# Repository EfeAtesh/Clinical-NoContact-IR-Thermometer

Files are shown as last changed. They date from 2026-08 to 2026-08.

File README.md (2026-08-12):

# Clinical Non-Contact Infrared Thermometer
> **Klinik Temassız Kızılötesi Termometre Projesi** (๑•̀ㅂ•́)و✧  
> *BME425 Biyomedikal Mühendisliği Projesi | Group 1 (01-MIY-2526S)*

---

## ( ° ᴗ ° ) Project Overview

This repository contains the design, hardware specifications, PCB Gerber files, 3D mechanical enclosure models, testing procedures, circuit schematics, physical prototype photos, etched PCB assembly images, and embedded C++ firmware for a **Clinical-Grade Non-Contact Infrared (IR) Thermometer**.

The device is engineered according to international medical device standards, specifically **EN ISO 80601-2-56:2017** (*Particular requirements for basic safety and essential performance of clinical thermometers for body temperature measurement*).

---

## (ノ◕ヮ◕)ノ*::・゜ Prototype & Hardware Gallery

| Handheld Prototype (Side View) | OLED Temperature Display |
| :---: | :---: |
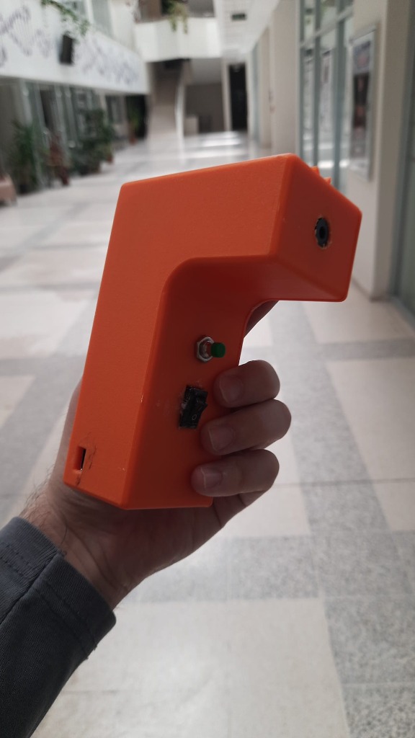
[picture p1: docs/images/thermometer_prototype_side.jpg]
Handheld Prototype
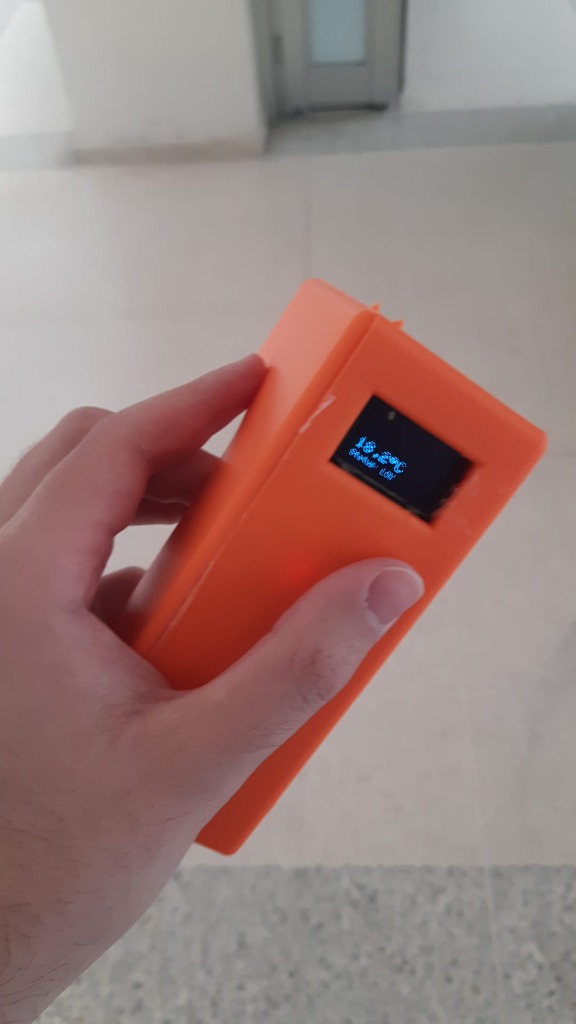
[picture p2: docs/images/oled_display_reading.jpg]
OLED Display
|  |  |
| *Ergonomic 3D enclosure with trigger button, power switch & IR sensor aperture* | *Real-time temperature readout (18.2 °C) & battery status on SSD1306 OLED* |

| Assembled PCB (Top / Component View) | Etched PCB (Bottom / Traces View) |
| :---: | :---: |
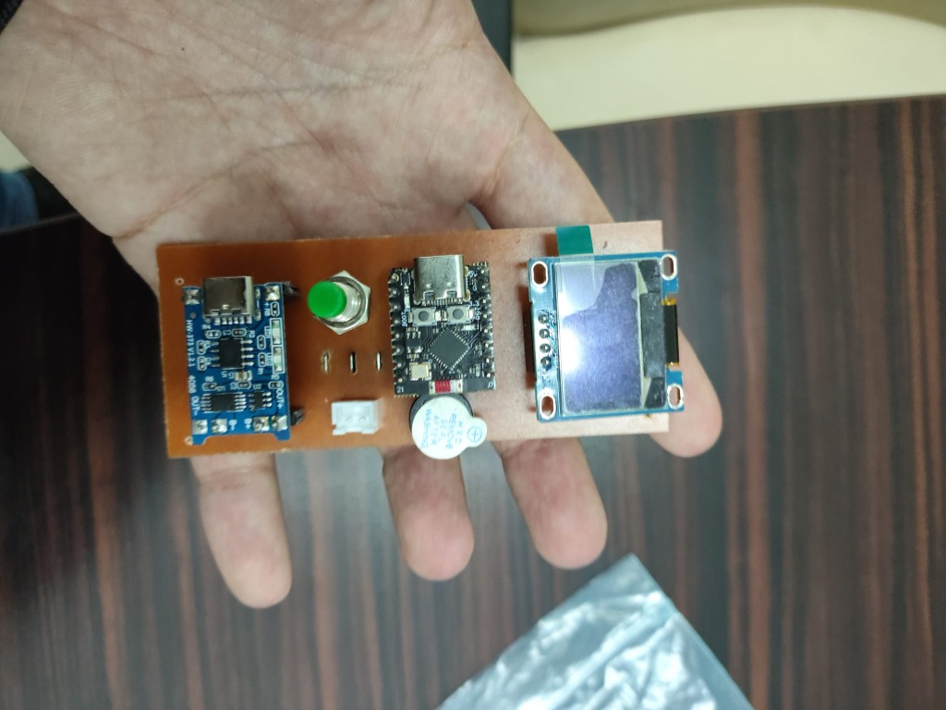
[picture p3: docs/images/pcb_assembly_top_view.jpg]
Assembled PCB
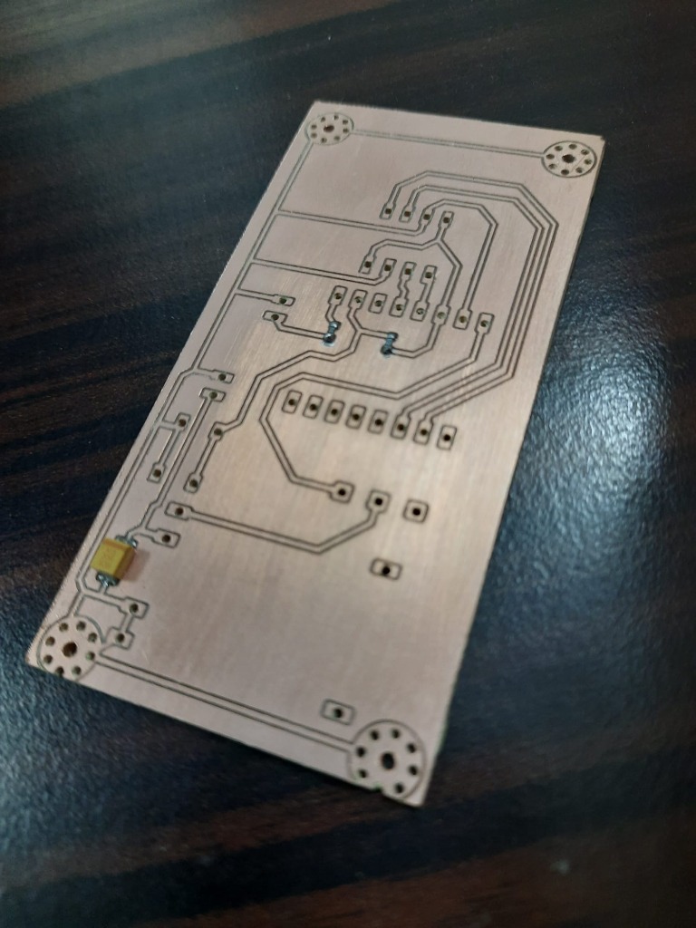
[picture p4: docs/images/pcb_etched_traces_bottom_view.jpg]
Etched PCB Traces
|  |  |
| *Fabricated control board with TP4056, ESP32-C3 Mini, SSD1306 OLED & Buzzer* | *Etched copper PCB traces showing component pads and SMD decoupling capacitors* |

| Circuit Schematic Diagram | Weight Verification (113.17 g) |
| :---: | :---: |
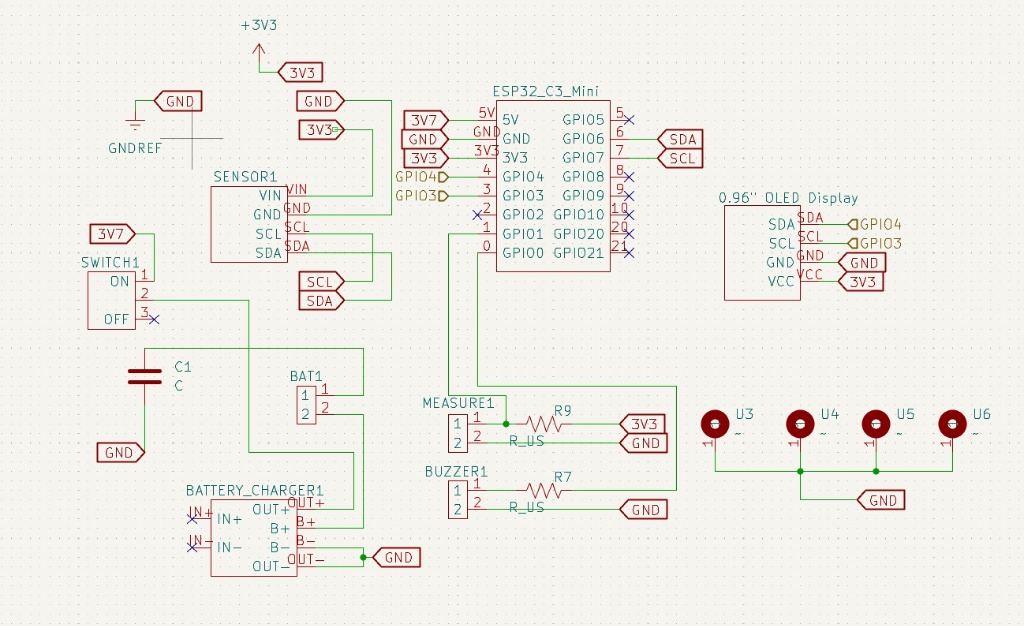
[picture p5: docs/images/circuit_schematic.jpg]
Circuit Schematic
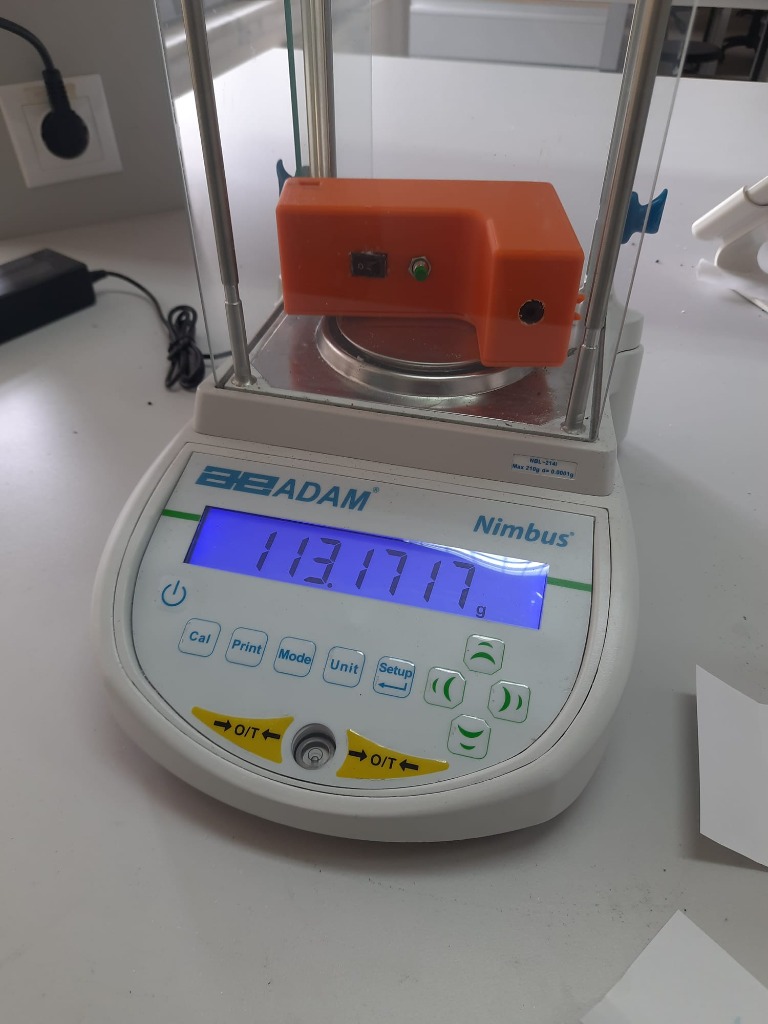
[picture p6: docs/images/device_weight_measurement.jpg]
Weight Measurement
|  |  |
| *KiCad schematic showing ESP32-C3, MLX90614, TP4056, OLED & Buzzer interconnections* | *Precision weight measurement using ADAM Nimbus digital scale (113.1717 g)* |

---

## (っ˘ω˘ς) Firmware & Software Architecture

The embedded system source code is structured under `firmware/` with **Clean Code** architecture principles:
- **Constants & Configuration**: Explicit pin maps (`PIN_I2C_SDA = 8`, `PIN_I2C_SCL = 9`, `PIN_BUTTON = 21`, `PIN_BUZZER = 0`) and fever threshold (`FEVER_THRESHOLD_C = 37.5°C`).
- **UI & Animations**: Boot thermometer filling animation (`playStartupAnimation()`), rotating loading spinner (`showLoadingSpinner()`), slide-in temperature display (`displayResultSlideIn()`), and non-blocking idle heartbeat pulse (`updateIdleHeartbeat()`).
- **Auditory Alerts**: Discrete button beep (`playButtonBeep()`) and 4-beep fever acoustic warning (`triggerFeverAlert()`).

### ( •̀ ω •́ )y Building & Flashing Firmware

#### Option A: PlatformIO (VS Code)
```bash
cd firmware
pio run --target upload
```

#### Option B: Arduino IDE
1. Open [`firmware/thermometer_firmware/thermometer_firmware.ino`](file:///Users/main/Desktop/Microsoft-Staj/Clinical-NoContact-IR-Thermometer/firmware/thermometer_firmware/thermometer_firmware.ino).
2. Install Required Libraries via Library Manager:
   - `Adafruit MLX90614 Library`
   - `Adafruit SSD1306`
   - `Adafruit GFX Library`
3. Select Board: **ESP32C3 Dev Module** (Baud Rate: 115200) and click **Upload**.

---

## ( •̀ ω •́ )✧ Key Specifications & Hardware Architecture

| Component | Description / Part Number | Interface / Specs |
| :--- | :--- | :--- |
| **Microcontroller Unit (MCU)** | ESP32-C3 Mini WiFi & Bluetooth LE Board | I2C / GPIO |
| **Infrared Temperature Sensor** | Melexis GY-906 / MLX90614 Non-Contact IR Sensor | I2C (SDA: GPIO8, SCL: GPIO9) |
| **Display Unit** | 0.96-inch SSD1306 OLED Graphic Display (128x64) | I2C |
| **Power Management** | TP4056 Type-C Lithium Battery Charger Module | Type-C 5V Input |
| **Battery** | Power-Xtra PX302030 3.7V 120mAh 1S Li-Polymer Battery | 3.7V DC |
| **Audio Notification** | 3–24V Active Electronic Buzzer | GPIO Alert Output (GPIO0) |
| **Total Mass** | 113.17 g (verified via laboratory balance) | Ergonomic Handheld |
| **Enclosure** | Custom Ergonomic 3D Printable Housing | Mechanical (`mechanical/`) |

---

## ⚡( ʘ ‿ ʘ )⚡ Circuit Schematic Highlights

The electrical system is designed around the **ESP32-C3 Mini** board:
- **Sensor Connection**: GY-906 (MLX90614) IR sensor communicates via I2C bus (`SDA` -> `GPIO8`, `SCL` -> `GPIO9`).
- **Display Connection**: 0.96" OLED display shares the I2C bus (`GPIO8`/`GPIO9`) powered at 3.3V.
- **Power Path**: 3.7V Li-Po battery connects through an ON/OFF Rocker Switch (`SWITCH1`) to `BATTERY_CHARGER1` (TP4056) and supplies power to the system.
- **Measurement Trigger**: `MEASURE1` tactile push button on `GPIO21` with pull-up resistor setup.
- **Audio Output**: `BUZZER1` active buzzer connected to `GPIO0` via current-limiting resistor `R7`.

---

## (っ•̀ω•́)っ✎⁾⁾ Repository Navigation Structure

```
Clinical-NoContact-IR-Thermometer/
├── README.md                                    # Main project documentation & specification guide
├── LICENSE                                      # CERN Open Hardware Licence v2 (CERN-OHL-P)
├── .gitignore                                   # OS & editor file exclusion rules
│
├── mechanical/                                  # 3D Mechanical Housing & Enclosure Files (.f3d, .stl, docs)
│   ├── Housing_Design_v10.docx                  # Enclosure design document
│   ├── Housing_Design_v10.pdf                   # Housing design specifications PDF
│   ├── Housing_Assembly.pdf                     # Enclosure assembly instructions
│   ├── Cover_Page.docx                          # Housing cover documentation
│   └── Cover_Page.pdf                           # Housing cover documentation PDF
│
├── firmware/                                    # Embedded C++ Firmware (Clean Code Architecture)
│   ├── platformio.ini                           # PlatformIO configuration & dependency file
│   ├── src/
│   │   └── main.cpp                             # C++ Main Firmware Source Code
│   └── thermometer_firmware/
│       └── thermometer_firmware.ino             # Arduino IDE Sketch File
│
├── hardware/                                    # Electrical & Electronic Engineering
│   ├── datasheets/                              # Component Datasheets
│   │   ├── ESP32-C3_Mini_Board.pdf              # ESP32-C3 MCU datasheet
│   │   ├── MLX90614_IR_Sensor.pdf               # MLX90614 IR temperature sensor datasheet
│   │   ├── SSD1306_OLED_Display.pdf             # SSD1306 0.96" OLED display datasheet
│   │   ├── TP4056_Battery_Charger.pdf           # TP4056 Li-Po charger datasheet
│   │   ├── Power-Xtra_PX302030_LiPo_Battery.pdf # 3.7V 120mAh LiPo battery datasheet
│   │   └── Active_Buzzer.pdf                    # Active electronic buzzer datasheet
│   │
│   └── pcb/                                     # Gerber PCB Fabrication Files
│       ├── Design-F_Cu.gbr                      # Top copper layer
│       ├── Design-B_Cu.gbr                      # Bottom copper layer
│       ├── Design-F_Mask.gbr                    # Top solder mask
│       ├── Design-B_Mask.gbr                    # Bottom solder mask
│       ├── Design-F_Silkscreen.gbr              # Top silkscreen
│       ├── Design-B_Silkscreen.gbr              # Bottom silkscreen
│       ├── Design-F_Paste.gbr                   # Top solder paste
│       ├── Design-B_Paste.gbr                   # Bottom solder paste
│       └── Design-Edge_Cuts.gbr                 # Board outline / edge cuts
│
├── docs/                                        # Documentation & Regulatory Files
│   ├── images/                                  # High-resolution prototype photos & schematics
│   │   ├── thermometer_prototype_side.jpg       # Handheld prototype photo
│   │   ├── oled_display_reading.jpg             # OLED temperature readout photo
│   │   ├── pcb_assembly_top_view.jpg            # Assembled PCB top view photo
│   │   ├── pcb_etched_traces_bottom_view.jpg    # Etched copper PCB bottom view photo
│   │   ├── circuit_schematic.jpg                # KiCad schematic diagram image
│   │   └── device_weight_measurement.jpg        # Digital scale weight measurement photo
│   │
│   ├── reports/                                 # Project plans, design descriptions & final reports
│   │   ├── BME425_Thermometer_Document.pdf      # Detailed thermometer design overview
│   │   ├── Final_Report_Group1.pdf              # Final capstone project report
│   │   ├── Project_Management_Plan.docx         # Project Management Plan (PMP)
│   │   ├── Design_Description.docx              # System Design Description
│   │   ├── System_Requirements.docx             # System requirements specification
│   │   ├── Preliminary_Design_Review.docx       # Preliminary Design Review (PDR)
│   │   ├── Configuration_Item_List.docx         # Configuration management item list
│   │   ├── Group1_Gantt_Chart.xlsx              # Project timeline & Gantt chart
│   │   └── Appendix.docx                        # Documentation appendix
│   │
│   ├── test-procedures/                         # Verification, Validation & Acceptance Testing
│   │   ├── Acceptance_Test_Procedure_ATP.pdf    # Acceptance Test Procedure (ATP)
│   │   ├── Verification_Validation_Test_Procedure_V2TP.pdf # V2TP test procedure
│   │   ├── Verification_Validation_Test_Plan.pdf# Verification & validation test plan
│   │   ├── Power_And_Control_Board_Assembly.pdf # Assembly guide for power/control board
│   │   ├── Assembly_Record.pdf                  # Device assembly records
│   │   ├── Verification_Validation_Test_Procedure_Template.docx # V2TP template
│   │   └── V2TP_Test_Datasheet.xlsx             # Test data recording spreadsheet
│   │
│   ├── standards/                               # Regulatory Medical Standards
│   │   ├── EN_ISO_80601-2-56-2017.pdf           # ISO standard for clinical thermometers (PDF)
│   │   └── EN_ISO_80601-2-56-2017.docx          # ISO standard reference document (Word)
│   │
│   └── sustainability/                          # Sustainability & Ethics Declarations
│       ├── UN_Sustainable_Development_Report.pdf# UN SDG alignment report
│       ├── UN_Sustainable_Development_Affirmation.docx # Sustainability affirmation
│       ├── Sustainable.docx                     # Sustainability impact analysis
│       └── Ethics_Declaration.docx              # Engineering ethics declaration
│   
│   
│
└── archive/                                     # Archival Storage
    └── duplicates/                              # Preserved previous draft versions & duplicates
```

---

## 🩺( ° Q ° ) Medical Standards Compliance

This project complies with **EN ISO 80601-2-56:2017**, which governs:
- Clinical accuracy and repeatability in non-contact body temperature measurements.
- Operational safety, thermal limit protections, and power management.
- Verification & Validation test procedure protocols (V2TP / ATP).

---

## ( ⚗_⚗ ) Verification & Acceptance Testing

Testing procedures are structured under `docs/test-procedures/`:
1. **Acceptance Test Procedure (ATP)**: Validates basic physical and electrical assembly requirements.
2. **Verification & Validation Test Procedure (V2TP)**: Verifies sensor calibration accuracy, thermal response time, audio alerts, and display output against reference laboratory thermometers.
3. **Mass Verification**: Total prototype weight verified at **113.17 g** using ADAM Nimbus precision scale.

---

## (📜 ❛ ֊ ❛) License & Attribution

This project is licensed under the **[CERN Open Hardware Licence Version 2 - Permissive (CERN-OHL-P)](LICENSE)**.  
Developed for **BME425 (01-MIY-2526S) Biomedical Engineering Project**. All rights reserved by Group 1 contributors.

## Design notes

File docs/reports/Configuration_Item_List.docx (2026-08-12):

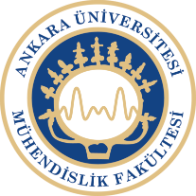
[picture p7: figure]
Inserting image...

Faculty of Engineering

Department of Biomedical Engineering

# Configuration List for The

# Non-Contact Clinical Thermometer

Part Number: 01-MIY-004

Rev-1

Date: 18/12/2025

# CHANGE RECORDS

# FIRST RELEASE

CREATED BY
Name | Title | Date Sign.

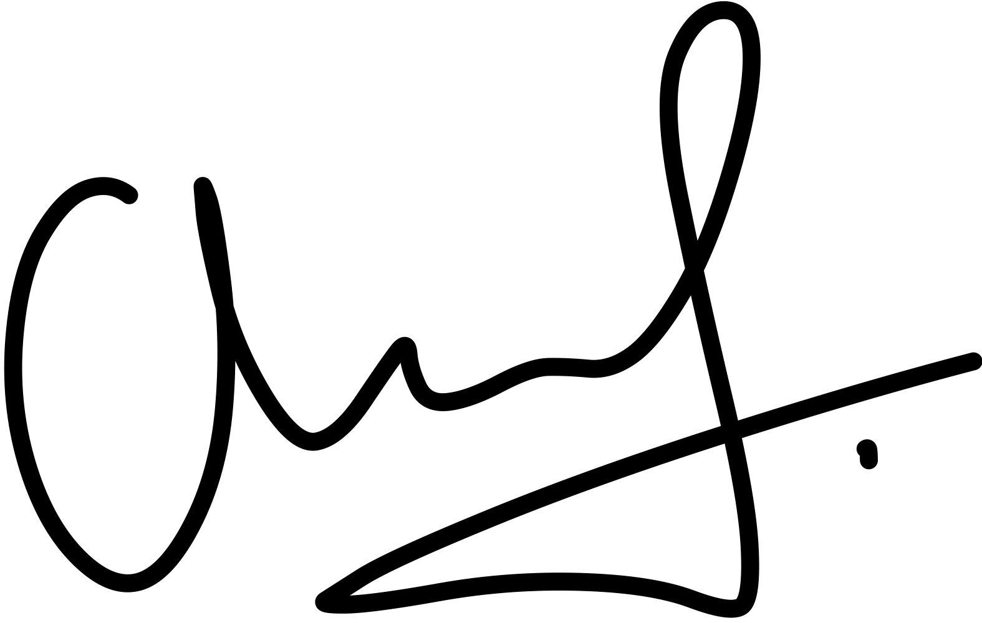
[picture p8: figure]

Augusta Nwosu | Electrical Engineer | 18.12.2025

CHECKED BY
Name | Title | Date Sign.
Fadime Taş | Quality Engineer | 18.12.2025

APPROVED BY
Name | Title | Date Sign.

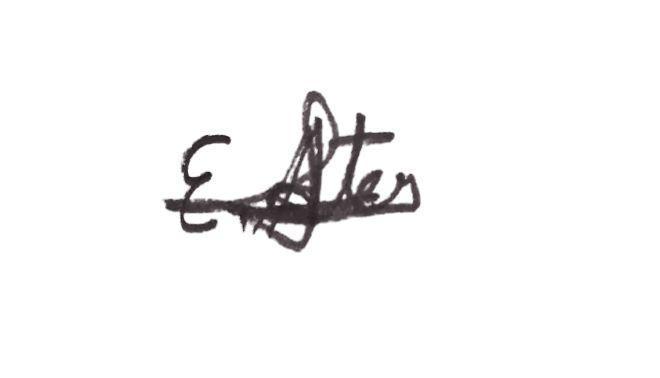
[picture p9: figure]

Efe Ateş | Program Manager | 18.12.2025

# REVISIONS

Rev. No | Change Description | Date | QA Approval

TABLE OF CONTENTS

FIRST RELEASE……………………………………………….………………………………………..2

REVISIONS……………………………………………………………………………………...2

1. PURPOSE…………………………………………………………………………………..4

2. SCOPE……………………………………………………………………………………… 4

3. CONFIGURATION ITEM LIST………………………………………………………….4

4. REFERENCES…………………………………………………………………………….. 5

1. PURPOSE

The purpose of the configuration item list for the non-contact type thermometer is to formally identify, document, and control all hardware and electronic components required for the development, assembly, and maintenance of the device. By listing each component with its corresponding part number and item description, the configuration item list ensures traceability, consistency, and accuracy throughout the product lifecycle. This documentation supports effective procurement, quality assurance, and change management by providing a single, authoritative reference that aligns design specifications with the actual components used in the thermometer.

2. SCOPE

The scope of the configuration item list covers all materials and components necessary for the non-contact thermometer, including sensing elements, electronic modules, mechanical parts, power components, and interconnections. For each item, the list provides the relevant part number, a clear description, and reference links to approved suppliers for purchasing the materials. The scope is limited to components that directly contribute to the functionality, assembly, and verification of the thermometer, and it serves as a reference for all engineers during design and manufacturing activities.

3. CONFIGURATION ITEM LIST

Table 1: Configuration Item List for Non Contact Thermometer

Item No | Part Number | Description
1 | 01-PRT-001 | MCU Kit, ESP32 C3 Mini
2 | 01-PRT-002 | MLX90614, Infrared Camera Sensor
3 | 01-PRT-003 | TP4056, Battery Charger Module
4 | 01-PRT-004 | Display Kit, 0.96” LCD Display
5 | 01-PRT-005 | On/Off Slider Switch
6 | 01-PRT-006 | Measurement Button
7 | 01-PRT-007 | Buzzer
8 | 01-PRT-008 | Resistor
9 | 01-PRT-009 | JST Connector
10 | 01-PRT-010 | Lithium Ion Battery
11 | 01-PRT-011 | Sensor PCB
12 | 01-PRT-012 | Housing Assembly

4. REFERENCES
1. Microcontroller – ESP 32 C3 super mini - https://www.direnc.net/esp32-c3-mini-wifi-bluetooth-modulu
2. Infrared camera sensor - MLX90614 - (https://www.robotistan.com/gy906-mlx90614-kizilotesi-sensoru-modulu?language=tr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)https://www.robotistan.com/gy906-mlx90614-kizilotesi-sensoru-modulu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
3. Battery charger – TP4056 - https://www.robotistan.com/tp4056-type-c-1s-37v-lipo-li-ion-pil-sarj-devresi
4. Battery and buzzer connector – JST connector - https://www.robotistan.com/ds1066-2mrw6xb-2-pin-90-derece-pcb-jst-konnektor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
5. LCD Display - (https://www.direnc.net/128x64-096-4-pin-oled-grafik-lcd-ekran-ssd1306-i2c-beyaz)https://www.direnc.net/128x64-096-4-pin-oled-grafik-lcd-ekran-ssd1306-i2c-beyaz
6. ON/OFF Slider Switch - https://www.direnc.net/surgulu-on-off-switch-180
7. Begin Measurement Button - https://www.direnc.net/6x6-05mm-tach-buton-4-bacak
8. Resistor – 1kohm, 10kohm - Buy 0R 5% 1W 2512 SMD Resistor at a Good Price - Direnc.net® (https://www.direnc.net/0r-5-1w-2512-smd-direnc-4000-adet)
9. Active Buzzer - 3-24V Circuit 22.6mm Ear Buzzer - Buy Black at a Reasonable Price - Direnc.net® (https://www.direnc.net/3-24v-devreli-40mm-kulakli-buzzer-siyah)

Doc. No: Part Number: 11-MIY-004 Configuration Item List for Non Contact Type Clinical Thermometer Rev:01 Page / ALL RIGHTS RESERVED. REPRODUCTION OR ISSUE TO THIRD PARTIES IN ANY FORM WHATEVER IS NOT PERMITTED WITHOUT WRITTEN AUTHORITY FROM THE PROPRIETORS.

ALL RIGHTS RESERVED. REPRODUCTION OR ISSUE TO THIRD PARTIES IN ANY FORM WHATEVER IS NOT PERMITTED WITHOUT WRITTEN AUTHORITY FROM THE PROPRIETORS.

MİKROELEKTRONİK, GÜDÜM VE ELEKTRO-OPTİK GRUBU MICROELECTRONICS, GUIDANCE AND ELECTRO-OPTICS DIVISION

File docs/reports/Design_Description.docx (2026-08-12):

Inserting image...

Faculty of Engineering

Department of Biomedical Engineering

# Non-Contact Type Clinical Thermometer

# Design Description

Part Number: 11-MIY-003

Rev-1

Date: 24/11/2025

# CHANGE RECORDS

## FIRST RELEASE

CREATED BY
Name | Title | Date Sign.
Gülşen Demir | System Engineer | 24.11.2025


Augusta Nwosu | Electrical Engineer | 24.11.2025

CHECKED BY
Name | Title | Date Sign.
Fadime Taş | Quality Engineer | 24.11.2025

APPROVED BY
Name | Title | Date Sign.

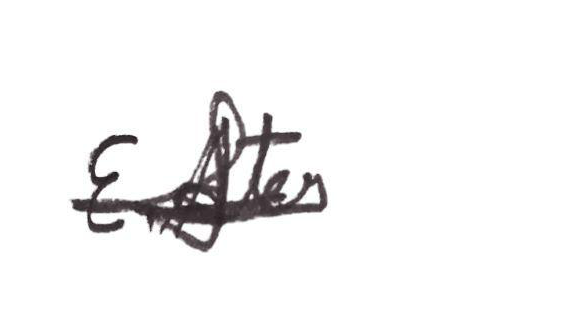
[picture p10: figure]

Efe Ateş | Program Manager | 24.11.2025

## REVISIONS

Rev. No | Change Description | Date | QA Approval

TABLE OF CONTENTS

CHANGE RECORDS 2

FIRST RELEASE 2

REVISIONS 2

1. SCOPE 4

2. DESCRIPTION 4

3.REFERENCES 5

4.SYSTEM ARCHITECTURE 6

4.1. PHYSICAL (BLOCK DIAGRAM) 6

4.2. FUNCTIONAL (OPERATION) 7

4.3. PRINCIPLE OF OPERATION 8

# 1. SCOPE

Body temperature is one of those basic but vital signs that tells us a lot about someone's health, right alongside blood pressure and pulse. These days, with hygiene concerns front and centre and the need for quick assessments, the old-fashioned contact thermometers feel slow and raise worries about spreading germs.

That's where a non-contact infrared thermometer comes in. You simply point it at someone's forehead from a short distance, and the infrared sensors do the rest, giving you an accurate reading instantly without ever touching the skin. It's a significant change for health monitoring.

# 2. DESCRIPTION

The non-contact thermometer measures forehead temperature by detecting infrared radiation emitted from the skin. This radiation is captured by the infrared camera module, where the IR sensors generate an analogue signal. The signal is immediately processed through an internal LNA, ADC, and DSP to produce accurate digital temperature data.

The processed signal is sent to the ESP32-C3 Mini, which performs final calculations and system control through its embedded firmware. After computing the temperature, the microcontroller transmits the result to the OLED display via serial communication, ensuring clear and fast visual output.

The device is powered by a rechargeable Li-ion battery. A dedicated charging circuit receives 5 V from a USB source and manages safe charging of the 3.7 V battery that runs the entire system. This enables fully portable operation.

User-interaction components, including the ON/OFF switch, buzzer, and reset button, are connected directly to the microcontroller for simple and reliable control. A USB programming interface on the ESP32-C3 Mini allows easy firmware updates when required.

This configuration provides a compact, efficient, and touch-free solution for quick and accurate forehead temperature measurement.

# 3.REFERENCES

3.1. 01-TRM-800: System Requirement Specification

3.2. ISO 80601-2-56:2017 : Particular requirements for basic safety and essential performance of clinical thermometers for body temperature measurement

3.3. IEC 60601–1:2005+A1:2012 : Medical electrical equipment - Part 1: General requirements for basic safety and essential performance

3.4. IEC 60601‐1‐2:2014 : Medical electrical equipment — Part 1-2: General requirements for basicsafety and essential performance — Collateral Standard: Electromagnetic disturbances ,Requirements and tests

3.5. ASTM E1965-98(2016) – Standard Specification for Infrared Thermometers for Intermittent Determination of Patient Temperature.

# 4.SYSTEM ARCHITECTURE

## 4.1. PHYSICAL (BLOCK DIAGRAM)

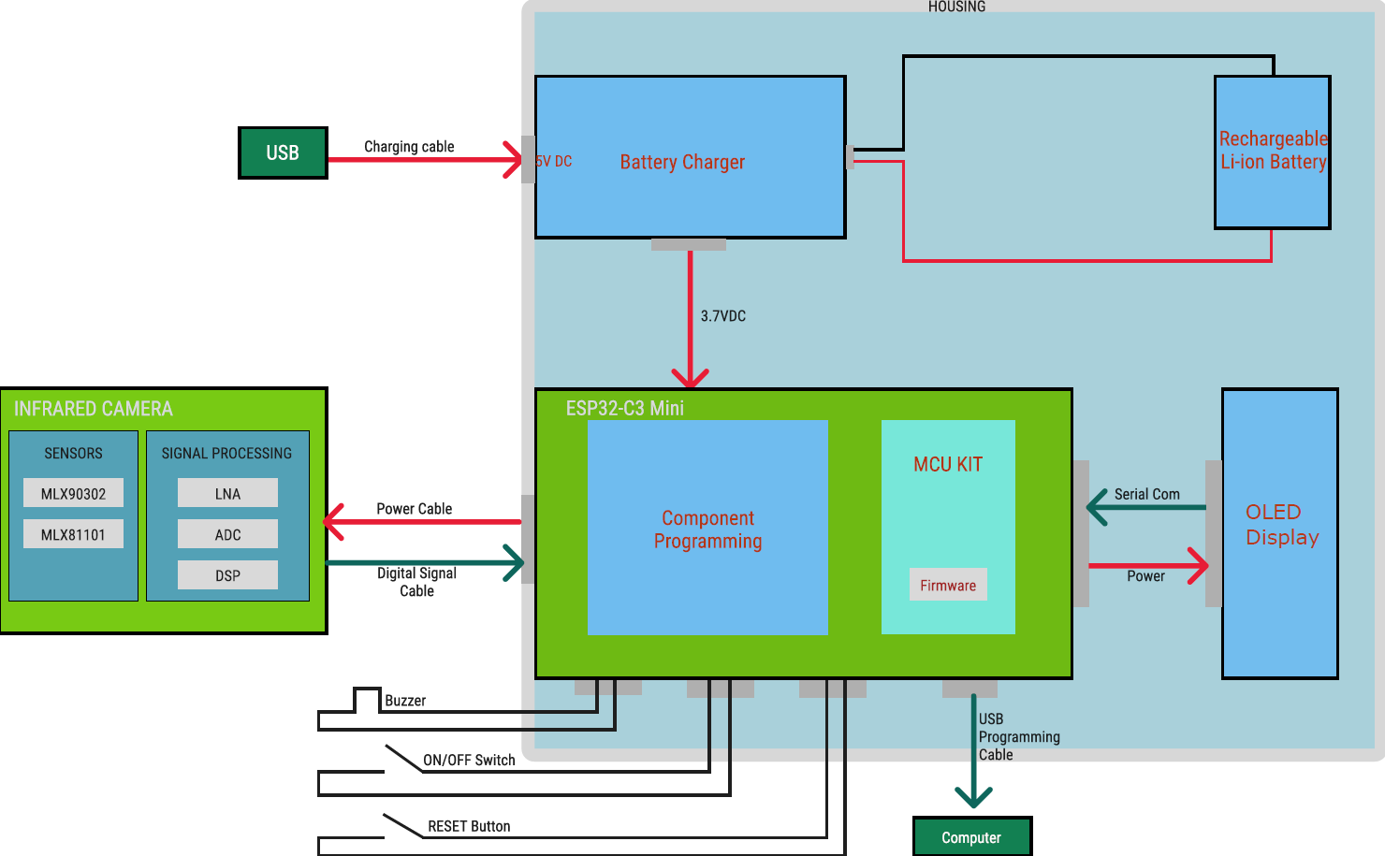
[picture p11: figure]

Figure 1:Block Diagram of The Design

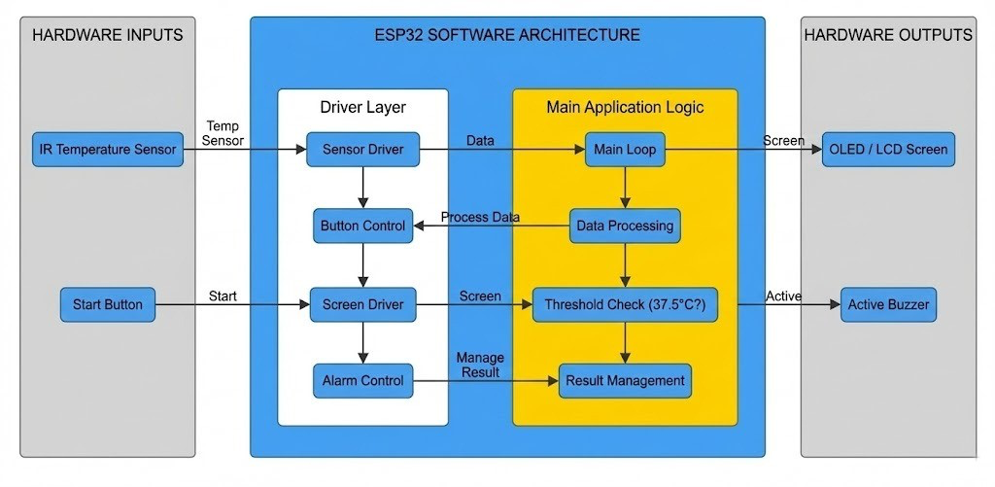
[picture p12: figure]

Figure 2:Software Design Diagram of The Design

## 4.2. FUNCTIONAL (OPERATION)

• While not in use, the thermometer can remain connected to the USB power source, allowing the battery-charging module to safely charge the internal Li-ion battery.
• Before taking a measurement, the user disconnects the USB cable (if desired) and powers on the device using the ON/OFF switch.
• The infrared camera module begins capturing emitted thermal radiation from the forehead and forwards the processed digital signal to the ESP32-C3 Mini.
• The microcontroller interprets the incoming data, executes the temperature-calculation algorithm, and prepares the final reading.
• The calculated temperature value is transmitted through serial communication to the OLED display for visual output.
• Once the reading is obtained, the buzzer activates briefly to inform the user that the measurement process is complete.
• Additional controls, such as the reset button, allow the user to restart the system if needed, and firmware updates can be performed using the USB programming interface.

## 4.3. PRINCIPLE OF OPERATION

- The designed non-contact thermometer measures body temperature from the forehead using an infrared camera module. Forehead measurement is selected because it allows fast, hygienic, and completely contact-free temperature assessment, which is especially suitable for elderly users and situations requiring strict hygiene.
- The system uses an infrared camera module that includes temperature-sensitive sensors (MLX90302, MLX81101) and an internal signal processing chain consisting of an LNA, ADC, and DSP. These components work together to detect the infrared radiation emitted from the forehead and convert it into digital temperature data.
- The infrared camera module sends digital temperature data through a power & data cable directly to the ESP32-C3 Mini microcontroller, eliminating the need for external analog circuits or amplifiers. Because the sensing unit already performs amplification, filtering, and ADC conversion internally, the microcontroller receives clean and processed data.
- The ESP32-C3 Mini acts as the main control unit. It receives measurement data from the camera, applies compensation algorithms, processes temperature values, and prepares the results to be displayed. Firmware inside the MCU performs noise reduction, ambient compensation, and final temperature calculation.
- System uses a rechargeable Li-Ion battery as its power source. The battery is charged through a 5 V USB power input, which feeds the battery charging module. The charging module safely manages the charging cycle and provides a stable 3.7 V DC output to power the ESP32-C3 Mini and other electronic elements.
- When the thermometer is unplugged, the Li-Ion battery continues powering the entire system. The ESP32-C3 Mini further regulates power internally to drive its logic circuits, the OLED display, and connected components.
- A 0.96-inch OLED Display is used to show the measured temperature clearly. OLED technology is chosen for its low power consumption, high contrast, and visibility under various lighting conditions.
- The thermometer includes user interface elements such as:

- Power button to turn the device ON/OFF

- RESET button for system restart

- USB programming cable connection for firmware updates and debugging

- Buzzer for acoustic feedback

- The buzzer alerts the user when the measurement process is complete, and the temperature value is ready to read on the display. This ensures ease of use, especially for elderly individuals.
- During measurement, the infrared camera detects the forehead temperature and communicates the processed digital data to the ESP32-C3 Mini. The microcontroller finalizes the computation and displays the temperature on the OLED screen within a short response time.
- Cable assemblies are used for system organization:
- Camera cable connects the infrared camera to the ESP32-C3 Mini.
- Battery cable connects the charging circuit to the Li-Ion battery and distributes power to the main PCB. These cables ensure mechanical flexibility and electrical integrity of the system.

Doc. No: 11-MIY-003 Design Description for Non-Contact Thermometer Rev:01 Page /9 ALL RIGHTS RESERVED. REPRODUCTION OR ISSUE TO THIRD PARTIES IN ANY FORM WHATEVER IS NOT PERMITTED WITHOUT WRITTEN AUTHORITY FROM THE PROPRIETORS.

ALL RIGHTS RESERVED. REPRODUCTION OR ISSUE TO THIRD PARTIES IN ANY FORM WHATEVER IS NOT PERMITTED WITHOUT WRITTEN AUTHORITY FROM THE PROPRIETORS.

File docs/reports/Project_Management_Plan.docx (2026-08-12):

Inserting image...

Faculty of Engineering

Department of Biomedical Engineering

Project Management Plan (PMP) for The Non-Contact Thermometer

Part Number: 01-MIY-001

Rev: 1

Date: 16/11/2025

# CHANGE RECORDS

## FIRST RELEASE

CREATED BY
Name | School Number | | Title | Date Sign.

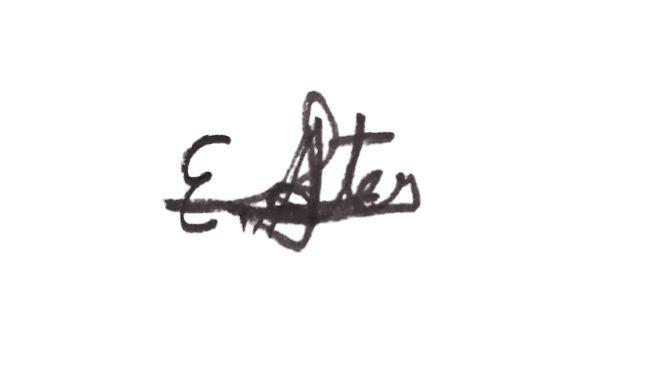
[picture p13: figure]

Efe Ateş | 22290588 | | Program Manager | 16.11.25
APPROVED BY
Name | School Number | | Title | Date Sign.


Augusta Nwosu | 21291005 | | Electronic Engineer | 17.11.25

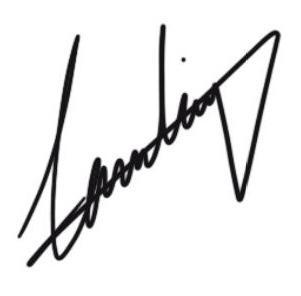
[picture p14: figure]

Ayşe Sarıkaya | 21290474 | | Mechanical Engineer | 18.11.25
Eren Can Kayabaşı | 21290445 | | Software Engineer | 17.11.25

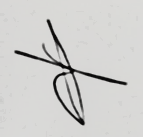
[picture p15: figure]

Fadime Taş | 21290304 | | QA Engineer | 16.11.25

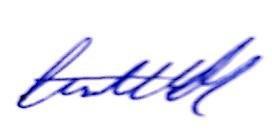
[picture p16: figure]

Furkan Bacak | 20291193 | | Production Engineer | 16.11.25
Gülşen Demir | 20291279 | | System Engineer | 16.11.25

## REVISIONS

Rev. No | Change Description | Date | QA Approval

TABLE OF CONTENTS

CHANGE RECORDS 2

FIRST RELEASE 2

REVISIONS 2

1. PURPOSE 5

2. SCOPE 5

3. REFERENCES 5

4. RESOURCES 6

5. TEAM ORGANIZATION, RESPONSIBILITIES, COMMUNICATION 6

5.1. ORGANISATION CHART 7

5.2. JOB DESCRIPTIONS, RESPONSIBILITIES 7

5.2.1. PROGRAM ENGINEER 7

5.2.2. SYSTEM ENGINEER 8

5.2.3. ELECTRONICS ENGINEER 8

5.2.4. MECHANICAL ENGINEER 9

5.2.5. PRODUCTION ENGINEER 9

5.2.6. SOFTWARE ENGINEER 10

5.2.7. QUALITY ASSURANCE ENGINEER 10

5.3. COMMUNICATION 11

6. WORK BREAKDOWN STRUCTURE (WBS) 11

6.1.1.1. PLANNING 12

6.1.0.1. REQUIREMENTS CAPTURE 12

6.1.1.0 WEIGHT 12

6.1.1.1 SURFACE 12

6.1.2. FUNCTIONAL REQUIREMENTS 13

6.1.2.1 OPERATING CONTROLS 13

6.1.2.2 POWER SUPPLY 13

6.1.2.3 UNITS OF MEASURE 13

6.1.2.4 RATED OUTPUT RANGE 13

6.1.2.5 ACCURACY 13

6.1.2.6 MEASUREMENT TIME 14

6.1.2.7 ALARM CONDITIONS 14

6.1.3 ENVIRONMENTAL CONDITIONS 14

6.1.3.1 OPERATING TEMPERATURE 14

6.1.3.2 STORAGE TEMPERATURE 14

6.1.4 USABILITY 15

6.1.4.1 DISPLAY SIZE 15

6.1.4.2 MEASURING SITE 15

6.2.0 PROJECT MANAGEMENT PLAN 15

6.2.1.0 DESIGN PHASE (CONCEPTUAL/DETAILED DESIGN) 15

6.2.1.1 PRELIMINARY DESIGN (CONCEPTUAL DESIGN) 16

6.2.2. DETAILED DESIGN 16

6.2.3. DESIGN RESEARCH FOR EPIDERMAL THERMAL RESPONSE 17

6.3. IMPLEMENTATION 18

6.3.1. PROTOTYPE PRODUCTION 18

6.3.2. VERIFICATION/VALIDATION 18

6.4. SUPPORTING PROCESS 19

6.4.1. QUALITY ASSURANCE 19

6.4.2. RISK MANAGEMENT 19

6.4.3. PROCUREMENT 20

6.4.4. CONFIGURATION MANAGEMENT 20

6.4.5. DESIGN REVIEWS 21

7. SCHEDULE 22

# 1. PURPOSE

Purpose of this Project Management Plan is to show organization and Engineering design of this upcoming Non-Contact Clinical Thermometer. This thermometer will provide bodily temperature information from any humans that data derived from nearest tissue and fascia beneath the tissues. This data will be gathered optically in means of Infra-Red lights and their reflections coming to the lens.

# 2. SCOPE

The goal of this project is to create a clinical thermometer that meets ISO 80601-2-56:2017's fundamental performance and safety requirements. With the aid of academic resources from the university, fourth-year students will carry out all tasks, and the project will be completed in two semesters. A prototype will be manufactured in the scope of this project using the detailed design data and verified/validated according to the inspection/test procedures written by design group.

Each student will pay effort on varying fields such: Electrical Design, Software, Production, Q&A, Mechanical, System engineering.

# 3. REFERENCES

  3.1. EN ISO 80601-2-56-2017: Requirements for basic safety and essential performance of clinical thermometers for body temperature measurement
  3.2. IEC 60601–1:2005+A1:2012: Medical electrical equipment - Part 1: General requirements for basic safety and essential performance
  3.3. ISO 9001: Quality management systems - Requirements
  3.4. IEC 60601‐1‐2:2014: Medical electrical equipment — Part 1-2: General requirements for basic safety and essential performance — Collateral Standard: Electromagnetic disturbances Requirements and tests
  3.5. ISO 14159: Safety of machinery — Hygiene requirements for the design of machinery
  3.6. ISO 14971: Medical devices – Application of risk management to medical devices
  3.7. IEC 60601‐1‐2:2014: Medical electrical equipment — Part 1-2: General requirements for basic safety and essential performance — Collateral Standard: Electromagnetic disturbances — Requirements and tests.
  3.8. IEC 60601‐1‐6:2010+A1:2013: Medical electrical equipment — Part 1-6: General requirements for basic safety and essential performance — Collateral Standard: Usability +Amendment 1:2013
  3.9. IEC 60601‐1‐11:2015: Medical electrical equipment — Part 1-11: General requirements for basic safety and essential performance — Collateral Standard: Requirements for medical electrical equipment and medical electrical systems used in the home healthcare environment.
  3.10. IEC 60601‐1‐12:2014: Medical electrical equipment — Part 1-12: General requirements for basic safety and essential performance — Collateral Standard: Requirements for medical electrical equipment and medical electrical systems intended for use in the emergency medical services environment.
  3.11. ISO 15223‐1:2016: Medical devices — Symbols to be used with medical device labels, labelling and information to be supplied — Part 1: General requirements.
  3.12. IEC 62366‐1:2015: Medical devices — Part 1: Application of usability engineering to medical devices
  3.13. IEC 60086-4, Primary batteries – Part 4: Safety of lithium batteries

# 4. RESOURCES

The human resources, seven engineering students will be sufficient to successfully complete the project. Allocation of work is as stated in the “job descriptions, responsibilities” section of this document. When necessary, allocation will be adjusted during the workflow.

Laboratories, workshops with equipments such as DMM, soldering iron, oscilloscope, power supplies etc. will be available at our university. Other equipments will be provided by our group or our advisor. Two semesters are expected to complete the whole project. At least one working prototype of clinical body thermometer is manufactured and tested for verification/validation and documented.

The money for materials, components and services is met by students.

# 5. TEAM ORGANIZATION, RESPONSIBILITIES, COMMUNICATION

Project teams constitute seven students selected for different tasks. Job descriptions and responsibilities are given in the following paragraphs as stated in start.

# 5.1. ORGANISATION CHART

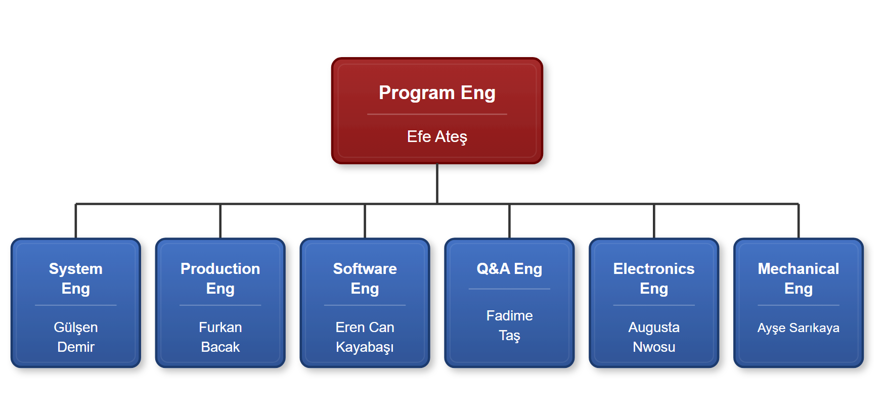
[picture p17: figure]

Figure-1: Structure of organization a non-contact clinical body thermometer

Engineers stated below part of chart will be administrated by Program Engineer. His role is making sure everyone doing their correspondence tasks at their times.

# 5.2. JOB DESCRIPTIONS, RESPONSIBILITIES

# 5.2.1. PROGRAM ENGINEER

- Prepares project management plan, including scheduling, finance, resources, milestones, reviews, and Earned Value Analysis (EVA).
- Monitors program objectives through design reviews.
- Manages program scheduling and execution, resolving cost, schedule, and quality challenges.
- Tracks risk management files for potential risks.
- Organize review sessions and write reports for program milestones.
- Maintains and prepares program documentation for audits. Uses EVA to track additional project activity over budget and schedule.
- Facilitates communication between management and team members.
- Collaborates with team members to overcome procurement, testing, and manufacturing restrictions such as cost, workshare, equipment, tooling, and facilities. Works with management and team members to eliminate procurement, test and manufacturing constraints including cost, workshare, equipment, tooling and facilities.
- Works with engineering (design engineers), quality, production and procurement to resolve non-conformances and contributes to mrb (material review board) meetings.

# 5.2.2. SYSTEM ENGINEER

- Prepares project management plan, including scheduling, finance, resources, milestones, reviews, and Earned Value Analysis (EVA).
- Monitors program objectives through design reviews.
- Manages program scheduling and execution, resolving cost, schedule, and quality challenges.
- Tracks risk management files for potential risks.
- Organize review sessions and author reports for program milestones.
- Maintains and prepares program documentation for audits.
- Uses EVA to track additional project activity over budget and schedule.
- Facilitates communication between management and team members.
- Collaborates with team members to overcome procurement, testing, and manufacturing restrictions such as cost, workshare, equipment, tooling, and facilities.

# 5.2.3. ELECTRONICS ENGINEER

- Works with system engineer for conceptual design
- Works with system engineer to prepare the conceptual design data (documents) like requirement specification, design description and configuration item list.
- Simulates the electronic circuits to be used in the project, using the simulation software like proteus, tina, electronic workbench etc.
- Investigates epidermal electronic devices/skin system, thermoregulation of human body.
- Makes the breadboard trials for electronic circuits.
- Designs the electronic circuits, creates the schematics and printed circuit board layouts if required.
- Designs the system software (firmware)
- Provides mechanical interfaces of electronic hardware to mechanical engineer.
- Recommends the measurement methods to test the hardware designed.
- Prepares the electronic hardware engineering drawings.
- Purchasing and kitting (material preparations, tinning, receiving inspection and test)

# 5.2.4. MECHANICAL ENGINEER

- Works with system engineer for conceptual design
- Works with system engineer to prepare the conceptual design data (documents) like requirement specification, design description and configuration item list.
- Designs the mechanical parts (like housing, battery compartment, probe tip etc.) in 3d cad software. Not only the single mechanical parts but the other parts also will be modelled using this software to be able to verify the interfaces of all parts.
- Installation and uninstallation of assemblies must be considered when designing the parts.
- Uses the 3D printing technique for rapid prototyping of mechanical parts.
- Investigates epidermal electronic devices/skin system, thermoregulation of human body and contribute to electronic and software engineer for temperature calculations.
- Designs and manufactures necessary tools and accessories when necessary.
- Provides necessary drawings to other design engineers for documentation or presentations.

# 5.2.5. PRODUCTION ENGINEER

- Assembling electronic components and perform inspections/testing for quality in the electronic assembly production task.
- Handling wiring connections for the Wiring assembly production task, verified through continuity testing.
- Obtaining QAE approval for the in-circuit test (ICT) to verify circuit functionality, assessed through Assembly Record review.
- Securing PE approval for Fabrication Tests (Fabtest) to ensure fabrication quality, with results documented in the Assembly Record.
- Applying operational/configurational markings correctly for the Marking task, verified by visual inspection.

# 5.2.6. SOFTWARE ENGINEER

- Prepares the initial firmware which will be uploaded into the MCU, by creating draft source code to communicate with the infrared sensor that will measure the temperature, providing basic functionality for the device to operate.
- Processes data by algorithms to convert the sensor data into clear temperature readings.
- Creates the code to control the display screen, which will show the measured temperature.
- Creates code to optimize the power consumption of the device. Also, coding user interaction, such as button presses.
- Prepares code documentation with comments beside the code for in depth explanation.
- For final software documentation, calibration and documentation of accuracy, regulatory compliance tests will be done.
- Verification/ validation tests will include testing the software modules individually, then testing the interaction between different software components to ensure it meets all the requirements.
- Tests the accepting range of the non-contact thermometer, to ensure that it is ready for release.
- Prepares the verification/validation test procedures.

# 5.2.7. QUALITY ASSURANCE ENGINEER

- Reviews requirements, technical specifications and design documents for approval
- Supports, designs, develops, and enhances test processes.
- Creates detailed, verification and validation test plan, approves the test procedures.
- Documents inspection and test results, offers improvements after analysis of test results and overall product quality.
- Collaborates with the design team on bug fixes.
- Executes audits to verify all the processes within the scope of this project comply with this project plan and applicable standards and procedures.
- Ensures the use of calibrated devices in test and measurements.
- Leads the Material Review Board for non-conforming materials.
- Keeps track of corrective actions to fix the bugs, failures, process related problems
- Acceptance Test Procedure (ATP)

# 5.3. COMMUNICATION

Communication may be carried out by e-mail for formal communication like meeting calls, technical information exchange, document transfer or through phone conversations for urgent cases. E-mails and phone numbers are given below. E-mails will be preferred since most of them can be used as input to the project records.

Job Name e-mail Phone Number

Electronic Engineer Augusta Nwosu nwosuaugustac@gmail.com +905436440761

Mechanical Engineer Ayşe Sarıkaya Sarikayaayse44@gmail.com +905070750572

Production Engineer Furkan Bacak furkanbacak00@gmail.com +905368763586

Program Engineer Efe Ateş efeates3300@gmail.com +905312209935

Software Engineer Eren Can Kayabaşı erencnkybs@gmail.com +905491749403

Q&A Engineer Fadime Taş fadimeibnisina@gmail.com +905516470514

System Engineer Gülşen Demir gultsn1127@gmail.com +905319482603

# 6. WORK BREAKDOWN STRUCTURE (WBS)

The object, the output of this project is the design data (Technical Data Package) of Clinical Body Thermometer. The structure of WBS with its work packages and expected work hours is given in Figure-1 and description of work packages is given in the following paragraphs.

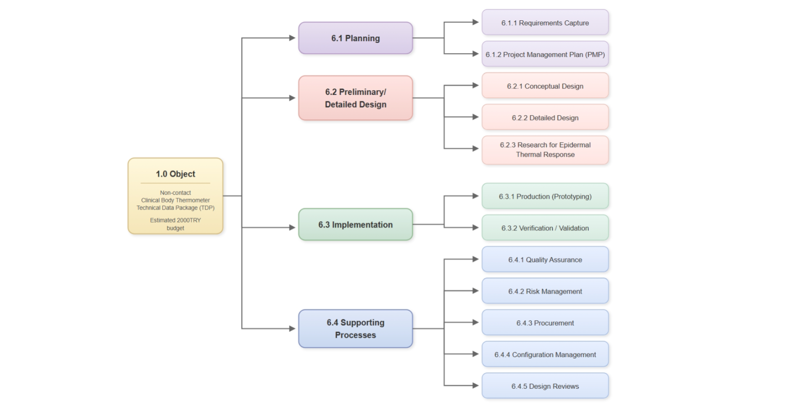
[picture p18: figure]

Figure-2: Work Breakdown Structure of designing a non-contact clinical body thermometer.

# 6.1.1.1. PLANNING

# 6.1.0.1. REQUIREMENTS CAPTURE

Process inputs: Standards in “References” section, customer expectations.

Process outputs: “Requirements Specification” document.

This section will specify what this design shall output and has specifications that will help to engineer this.

non-contact temperature.

# 6.1.1.0 WEIGHT

The non-contact clinical thermometer will be 50 grams to 400 grams maximum.

# 6.1.1.1 SURFACE

The non-contact thermometer’s surface will be smooth, durable and designed to be cleaned when needed. It must feel good on hand and people must feel the quality.

# 6.1.2. FUNCTIONAL REQUIREMENTS

# 6.1.2.1 OPERATING CONTROLS

The non-contact thermometer shall feature a minimal, user-friendly control interface (including elders), with no more than two buttons: a power button, a measurement button. Buttons shall be very easy to click and could be silent switch.

# 6.1.2.2 POWER SUPPLY

Supply should be provided from battery. The charging section should have battery production and must support 1A current. Charging section shall stop charging when battery has level of 100% charge and shall notify the user when its level reached full.

# 6.1.2.3 UNITS OF MEASURE

The non-contact thermometer will display the temperature in degrees Celsius ℃.

# 6.1.2.4 RATED OUTPUT RANGE

The output temperature of the non-contact thermometer shall measure from 25,0 °C to 45,0 °C.

# 6.1.2.5 ACCURACY

The accuracy of the non-contact thermometer will provide an accuracy of ±0.3 °C.

# 6.1.2.6 MEASUREMENT TIME

The measurement time shall be between 0 to 1 seconds.

# 6.1.2.7 ALARM CONDITIONS

Alarm conditions are optional. If value is above acceptable range (more than 39.5 degrees Celsius) it must alert using buzzer on board. This will express the situation’s emergency.

# 6.1.3 ENVIRONMENTAL CONDITIONS

# 6.1.3.1 OPERATING TEMPERATURE

The thermometer should operate in standard conditions with a range of 15°C to 80°C.

# 6.1.3.2 STORAGE TEMPERATURE

The thermometer should be suitable for storage at temperatures between -20°C and 90°C without damage.

# 6.1.4 USABILITY

# 6.1.4.1 DISPLAY SIZE

Character size will be greater than 4 mm for users to read easily. The screen must be an OLED. If it is an OLED display it shall be more than one colour and it shall be more than 0.96 inches. It shall work on <3.3 V DC voltage difference range. I2C communication protocol could be used or other favored communication protocol.

# 6.1.4.2 MEASURING SITE

The non-contact thermometer will have used and pointed on the forehead as a measuring site to read body temperature. To read the temperature correctly it should be within the distance of 1 to 5 cm from the forehead.

# 6.2.0 PROJECT MANAGEMENT PLAN

Process inputs: Requirements Specification

Process outputs: “Project Management Plan” document.

The design life cycle processes (Defining Requirements, Conceptual Design, Detailed Design, Implementation) clearly defined in this Project Management Plan including the activities, milestones, risk assessment, inputs, outputs and responsibilities.

Standards for design processes selected and defined in the plan.

Responsibilities for supporting processes have also been defined for smooth transition between the phases and to assure product quality, reliability, safety.

# 6.2.1.0 DESIGN PHASE (CONCEPTUAL/DETAILED DESIGN)

Design phase includes mainly two work packages: Preliminary Design showing the basic configuration items and their relations and Detailed Design consisting of final design of all assemblies, software, discrete parts and their tests.

# 6.2.1.1 PRELIMINARY DESIGN (CONCEPTUAL DESIGN)

Process inputs: “Requirement Specification” document

Process outputs: “Design Description”, “Configuration Item List” documents and Preliminary Design Review meeting report

The Preliminary Design process produces a high-level design concept to meet the requirements. The input to this process is Requirement Specification.

Preliminary Design can be accomplished using functional block diagrams, design and architecture descriptions, circuit card assembly outlines. A high-level description should be generated for the hardware item. This will include the architectural constraints, component over-stress, reliability, usability, safety, constraints on software or other system components. Configuration Items and major components should be identified at this stage.

Change control for the configuration items should be started when they are defined. To be able to track the changes, each configuration item shall have a item Part Number to establish a base line.

At this phase specific research studies may be performed to have necessary design documentation. To do this, breadboard designs may be done, simulation tools may be used.

When everything is ready to start to detailed design, a Preliminary Design Review will be realised to review the records, documents, and plans if all planned tasks are completed.

The outputs from this process are Design Description, Configuration Item List and Preliminary Design Review meeting report.

# 6.2.2. DETAILED DESIGN

Process inputs: “Design Description”, “Configuration Item List” documents

Process outputs: Assembly documents containing circuit schematics, component placement, Bill of Materials (BOM), CAD/CAM files (Gerber, STL, etc.), working brassboard level prototype thermometer, Critical Design Review meeting report, draft system software

The inputs to this process are Requirement Specification, Design Description, Configuration Item List and Preliminary Design Review meeting report.

Detailed electrical interfaces, mechanical interfaces software interfaces and user interfaces shall be defined and documented on assembly documents. Schematics of electronic assemblies are designed using electronic design automation softwares (EDA softwares like orcad, eagle, altium). Mechanical parts are designed with the help of Computer Aided Design (CAD) programs (like Pro-engineer, Solidworks, Catia, Inventor). The operation of electronic boards and mechanical parts/assemblies designed can be verified with simulation tools.

The materials required for detailed design procured, inspected/tested and datasheets obtained. The information in datasheets are very important in design work.

Easy installation and dis-installation, part (e.g battery) replacement, ergonomy and safety shall be considered when designing the mechanical parts and electronic circuits.

Necessary manufacturing files to manufacture the parts in house or to order shall be created both for Printed Circuit Boards and mechanical parts like Gerber Files, STL files. Mechanical parts are preferred to be manufactured by 3D printer in house.

Tests and other inspection activities shall be performed for each assembly to verify the compliance with the requirements.

A brassboard level prototype shall be produced and draft system software shall be coded during this design phase.

Note: Brassboard level prototype is a near final design circuit, built in a configuration which is representative of the final project, using similar construction methods and materials as the final project. It is between breadboard level prototype and engineering prototype where an engineering prototype is fully representative of the final product using approved components and suitable for complete evaluation of form, design and performance.

Documents including engineering drawings, bill of materials (BOM), component specifications, test procedures shall be prepared and change control activities shall be started for each new document.

Critical Design Review will be performed on this design documentation.

# 6.2.3. DESIGN RESEARCH FOR EPIDERMAL THERMAL RESPONSE

Process inputs: Working brassboard level thermometer, draft system software

Process outputs: Final system software, a white paper documenting the research results

The most challenging aspect of thermometer design is thermal response of skin and part of the thermometer contacting the body, especially for contact type thermometers. Although it is difficult to find sufficient data in literature, investigations shall be made in the internet and printed publications on this subject. If sufficient information can not be obtained from the literature, a research will be realized to obtain the necessary data to use in the calculations performed by microcontrollers enabling them to display correct body temperature.

The scope of work in this regard is limited with measurements in different ambient temperatures. The data including ambient temperature measured with a reference thermometer, measuring site temperature and reference body site temperature measured both by prototype thermometer and a reference clinical thermometer is collected. Data is analysed, correlation is established between ambient temperature and body temperature and a correction is made on the formula used in software.

# 6.3. IMPLEMENTATION

After successful completion of Critical Design Review, the implementation process will be started using the documents prepared at detailed design phase to produce the hardware item (Engineering Prototype)

This phase consists of production of engineering prototypes and qualification tests run on this prototype.

# 6.3.1. PROTOTYPE PRODUCTION

Process inputs: Assembly documents containing circuit schematics, component placement, Bill of Materials (BOM), CAD/CAM files (Gerber, STL, etc.), working brassboard level thermometer, Critical Design Review meeting report, draft system softare

Process outputs: Engineering Prototype which the verification/validation activities conducted with

An engineering prototype will be build using engineering drawings prepared during the detailed design process. The inputs to this process are assembly/part drawings including Bill Of Material (BOM), CAD files, Critical Design Review meeting report.

Missing parts are procured from suppliers or manufactured inhouse and the installation will start with the guidance of experienced engineers. Installation instructions will be created during the production and the drawings may be revised due to these instructions if necessary.

When required, special test set-up’s may be established for assemblies and sub-assemblies during the production of thermometer. The non-conformances will be documented and necessary corrective actions will be taken before proceeding.

An Acceptance Test Procedure will be created for the finished product to use before and during the Verification/Validation. The prototype production is completed only when the prototype passes the acceptance test successfully.

# 6.3.2. VERIFICATION/VALIDATION

Process inputs: Engineering Prototype with final system software, verification and validation test plans

Process outputs: Verification/validation report, Technical Data Package

The acceptance test is not intended to verify all requirements. Requirements which are not verified at acceptance test will be verified during the Verification Process.

Verification consists of reviews, analyses and laboratory tests (including the acceptance test) applied as defined in the Qualification Plan. The verification process should include an assessment of the results. After succesful completion of verification, Validation prosses in the field shall be applied to ensure that the requirements are correct and complete for intended use.

# 6.4. SUPPORTING PROCESS

# 6.4.1. QUALITY ASSURANCE

Process inputs: Project Management Plan, verification and validation test plans

Process outputs: Problem/Corrective Action Reports, MRB records, Audit records

Quality/Process assurance ensures that the life cycle process objectives are met and activities have been completed as outlined in plans or that deviations have been addressed.

Hardware design problems, process non-compliance with hardware plans and standards, and deficiencies in hardware life cycle data will be identified, documented and resolved by means of the Problem Reports. The purpose of problem reporting, tracking and corrective action is to record problems and ensure correct disposition and resolution. Problems may include non-compliance with plans and standards, deficiencies of life cycle process outputs, anomalous behavior of products, and inadequacy or deficiency of tools and technology processes.

# 6.4.2. RISK MANAGEMENT

Process inputs: Safety requirements, schedule, resources, budget

Process outputs: Risk Management Files

Responsibility: Program Engineer

The potential risks associated with harm to people and damage to property or the environment like threat of human errors (usability), wrong measurements are identified with the collective work of team members and defined at the end of the conceptual design phase.

Once risks have been identified, they must then be assessed as to their potential severity of impact (generally a negative impact, such as damage or loss) and to the probability of occurrence. For each potential risk, a risk management file is created to track the status of the risk. The risk management file contains the description of the risk, its impact, probability of occurrence, the actions to mitigate the risk to an acceptable level.

The risk management files are kept by program engineer as evidence of acceptable risk management process, required by most regulatory bodies.

The analysis in this project shall consider the risks of changing environmental conditions for the clinical thermometer and provide guidance regarding the residual risks in the instruction for use.

Also Hygiene risks to the consumer are important especially for contact type thermometers and shall be included in risk management files.

# 6.4.3. PROCUREMENT

Process inputs: Configuration Item List, BOM, schedule, resources, budget

Process outputs: Orders, components, nonconforming materials

Responsibility: Electronics Engineer

The procurements need to remain within the expenditure budget.

All records need to be kept for each order and must be kept in the correct auditable manner.

Procurements should be consistent with ethics and social responsibility and best practices and adherence to all laws and regulations is a strict requirement. Selection of the vendor depends on the cost and delivery time.

Risk analysis should be made especially for the materials supplied from abroad for delivery time.

The material supplied shall be inspected and or tested for identification and hazards.

# 6.4.4. CONFIGURATION MANAGEMENT

Process inputs: Configuration Baseline, engineering changes

Process outputs: Change orders, Revised Documents

Responsibility: Production Engineer

The configuration management process is intended to provide the ability to consistently replicate the configuration item, regenerate the information if necessary and modify the configuration item in a controlled fashion if modification is necessary.

Configuration items should be uniquely identified (e.g part number), documented and controlled and baselines should be established at the end of Conceptual Design phase as the “Configuration Item List” document. The purpose of baseline establishment is to define a basis for further activities and allow reference to, control of and traceability between configuration items.

Intermediate baselines may be established to aid in controlling hardware activities. Once a baseline is established it should be subject to change control procedures.

The purpose of the change control activity is to ensure the recording, evaluation, resolution and approval of changes. Change control should be started no later than the establishment of the baseline. Each change shall be recorded with its revision number, described on related documents and approved by quality assurance and program engineer.

# 6.4.5. DESIGN REVIEWS

Process inputs for PMR: “Design Description”, “Configuration Item List”, “Requirement Specification”

Process inputs for CMR: Assembly documents CAD/CAM files working brassboard level thermometer, Critical Design Review meeting report, draft system software

Process outputs: PMR, CMR reports

Responsibility: Program Engineer

Design reviews will be performed and documented as a review report, at multiple times during the project to determine that the design documents and implementation satisfy the requirements. All Project team members contribute to design reviews.

At least, the Preliminary Design Review is performed at the end of conceptual design and the Critical Design Review is performed when the detailed design with its design data is completed. Additional reviews may be carried out if necessary. Design reviews will check at least the following.

Minimum design data which shall be ready at Preliminary Design Review are;

· System Requirement Specification document

· Design Description document

· Configuration Item List document

Minimum design data which shall be ready at Critical Design Review are;

· Drawings for configuration items (schematics, layouts, assembly documents, solid model of designed parts, Bill Of Materials, system software)

· Working breadboard level thermometer

· Test/inspection results

· Risk management files

· Audit records

· Corrective Action reports

# 7. SCHEDULE

The project flow is shown in Figure-3

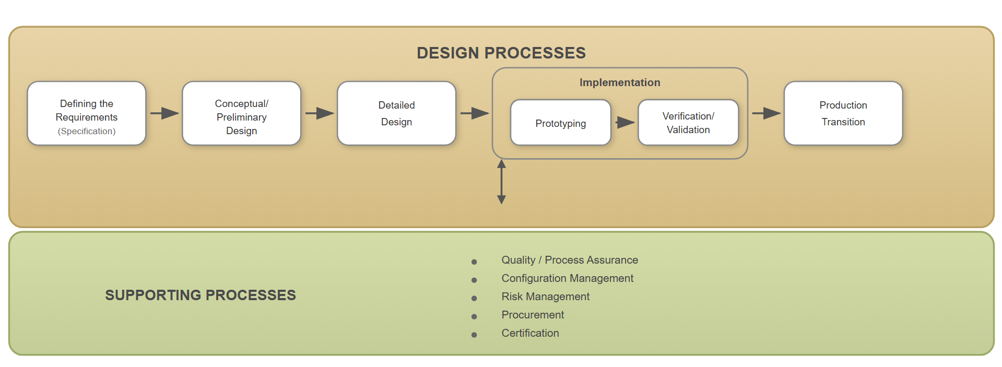
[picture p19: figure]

Figure-3: Design flow showing basic design activities

The Gantt chart given in Figure-4 shows the description and duration of tasks for scheduling. It has two main parts, a task list on the left side and a project timeline on the right.

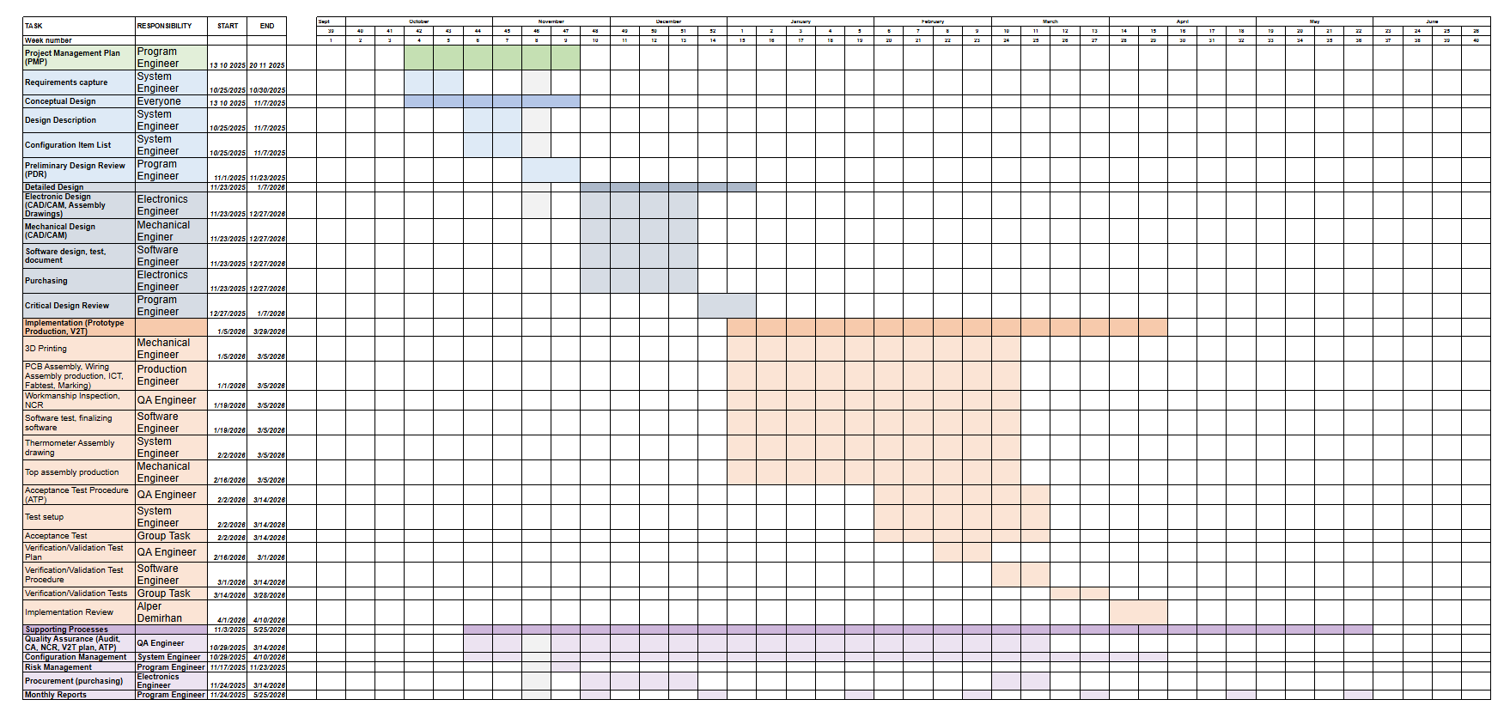
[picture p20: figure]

Figure-4: Gantt Chart for Non-Contact Thermometer Project

Doc. No: 11-MIY-001 Project Plan for Non-Contact Clinical Thermometer Rev:01 Page / ALL RIGHTS RESERVED. REPRODUCTION OR ISSUE TO THIRD PARTIES IN ANY FORM WHATEVER IS NOT PERMITTED WITHOUT WRITTEN AUTHORITY FROM THE PROPRIETORS.

ALL RIGHTS RESERVED. REPRODUCTION OR ISSUE TO THIRD PARTIES IN ANY FORM WHATEVER IS NOT PERMITTED WITHOUT WRITTEN AUTHORITY FROM THE PROPRIETORS.

MİKROELEKTRONİK, GÜDÜM VE ELEKTRO-OPTİK GRUBU MICROELECTRONICS, GUIDANCE AND ELECTRO-OPTICS DIVISION

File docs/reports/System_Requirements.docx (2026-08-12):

Inserting image...

Faculty of Engineering

Department of Biomedical Engineering

# System Requirements for Non-Contact Type Clinical Thermometer

Part Number:01-MIY-002

Rev-1

Date:24/11/2025

## CHANGE RECORDS

FIRST RELEASE

CREATED BY
Name | Title | Date Sign.
Gülşen Demir | System Engineer | 24.11.2025

CHECKED BY
Name | Title | Date Sign.
Fadime Taş | Quality Engineer | 24.11.2025

APPROVED BY
Name | Title | Date Sign.
Efe Ateş | Program Manager | 24.11.2025

REVISIONS

Rev. No | Change Description | Date | QA Approval

TABLE OF CONTENTS

CHANGE RECORDS 2

1. PURPOSE 4

2. SCOPE 4

3. REFERENCES 4

4. REQUIREMENTS 5

4.1 PHYSICAL REQUIREMENTS 5

4.1.1 WEIGHT 5

4.1.2 SURFACE 5

4.2. FUNCTIONAL REQUIREMENTS 5

4.2.1. OPERATING CONTROLS 5

4.2.2. POWER SUPPLY 5

4.2.3. UNITS OF MEASURE 6

4.2.4. RATED OUTPUT RANGE 6

4.2.5. ACCURACY 6

4.2.6. MEASUREMENT TIME 6

4.2.7. ALARM CONDITIONS 6

4.3. ENVIRONMENTAL CONDITIONS 6

4.3.1. OPERATING TEMPERATURE 6

4.3.2. STORAGE TEMPERATURE 7

4.4. USABILITY 7

4.4.1. DISPLAY SIZE 7

4.4.2. MEASURING SITE 7

# 1. PURPOSE

The purpose of this report is to define exactly what the thermometer must do, how well it must do it, and under what constraints, ensuring that the final device is safe, accurate, reliable, and meets the intended user needs.

# 2. SCOPE

The first step in building a reliable clinical non-contact thermometer is figuring out exactly what it needs to do and how well it needs to do it. This means deciding on the infrared technology you'll use, which features are must-haves versus nice-to-haves and understanding the real-world conditions where the device will be used. You'll need to think through things like how accurate the readings should be, how far away the sensor can work, how quickly it responds, whether it needs calibration, what diagnostics to include, how users will interact with it, power requirements, and the physical design itself.

Getting these requirements nailed down early saves a lot of headaches later. It helps ensure the thermometer will work the way clinicians expect while also satisfying regulators. Industry standards are helpful here because they give you a framework for capturing what matters, along with proven approaches for designing the system. They also guide you in setting up the testing and validation work that proves your thermometer is safe and performs as intended.

# 3. REFERENCES

3.1. IEC 60601–1:2005+A1:2012: Medical electrical equipment - Part 1: General requirements for basic safety and essential performance

3.2. IEC 60601‐1‐2:2014: Medical electrical equipment — Part 1-2: General requirements for basic safety and essential performance — Collateral Standard: Electromagnetic disturbances Requirements and tests

3.3. ISO 80601-2-56:2017: Part 2-56: Particular requirements for basic safety and essential performance of clinical thermometers for body temperature measurement

3.4. ISO 9001: Quality management systems - Requirements

# 4. REQUIREMENTS

# 4.1 PHYSICAL REQUIREMENTS

# 4.1.1 WEIGHT

The non-contact clinical thermometer will be 50 grams to 400 grams maximum.

# 4.1.2 SURFACE

The non-contact thermometer’s surface will be smooth, durable and designed to be cleaned when needed. It must feel good on hand and people must feel the quality.

# 4.2. FUNCTIONAL REQUIREMENTS

# 4.2.1. OPERATING CONTROLS

The non-contact thermometer shall feature a minimal, user-friendly control interface (including elders), with no more than two buttons: a power button, a measurement button. Buttons shall be very easy to click and could be silent switch.

# 4.2.2. POWER SUPPLY

Supply should be provided from battery. The charging section should have battery production and must support 1A current. Charging section shall stop charging when battery has level of 100% charge and shall notify the user when its level reached full.

# 4.2.3. UNITS OF MEASURE

The non-contact thermometer will display the temperature in degrees Celsius ℃

# 4.2.4. RATED OUTPUT RANGE

The output temperature of the non-contact thermometer shall measure from 25,0 °C to 45,0 °C.

# 4.2.5. ACCURACY

The accuracy of the non-contact thermometer will provide an accuracy of ±0.3 °C.

# 4.2.6. MEASUREMENT TIME

The measurement time shall be between 0 to 1 seconds.

# 4.2.7. ALARM CONDITIONS

Alarm conditions are optional. If the value is above acceptable range (more than 39.5 degrees Celsius) it must alert using a buzzer on board. This will express the situation’s emergency.

# 4.3. ENVIRONMENTAL CONDITIONS

# 4.3.1. OPERATING TEMPERATURE

The thermometer should operate in standard conditions with a range of 15°C to 80°C

# 4.3.2. STORAGE TEMPERATURE

The thermometer should be suitable for storage at temperatures between -20°C and 90°C without damage.

# 4.4. USABILITY

# 4.4.1. DISPLAY SIZE

Character size will be greater than 4 mm for users to read easily. Screen must be an OLED. If it is OLED display it shall be more than one colour and it shall be more than 0.96 inches. It shall work on <3.3 V DC voltage difference range. I2C communication protocol could be used or other favored communication protocol.

# 4.4.2. MEASURING SITE

The non-contact thermometer will have used and pointed on the forehead as a measuring site to read body temperature. To read the temperature correctly it should be within the distance of 1 to 5 cm from the forehead.

Doc. No: 11-MIY-002 System Requirements for Non-Contact Thermometer Rev-01 Page /7 ALL RIGHTS RESERVED. REPRODUCTION OR ISSUE TO THIRD PARTIES IN ANY FORM WHATEVER IS NOT PERMITTED WITHOUT WRITTEN AUTHORITY FROM THE PROPRIETORS.

ALL RIGHTS RESERVED. REPRODUCTION OR ISSUE TO THIRD PARTIES IN ANY FORM WHATEVER IS NOT PERMITTED WITHOUT WRITTEN AUTHORITY FROM THE PROPRIETORS.

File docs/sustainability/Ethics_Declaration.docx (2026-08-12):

Inserting image...

Faculty of Engineering

Department of Biomedical Engineering

# Ethics Declaration for The

# Non-Contact Clinical Thermometer

Part Number: 01-MIY-007

Rev-1

Date: 18/12/2025

# CHANGE RECORDS

## FIRST RELEASE

CREATED BY
Name | Title | Date Sign.
Gülşen Demir | System Engineer | 18.12.2025


Augusta Nwosu | Electrical Engineer | 18.12.2025

CHECKED BY
Name | Title | | Date Sign.
Fadime Taş | Quality Engineer | | 18.12.2025

APPROVED BY
Name | Title | | Date Sign.

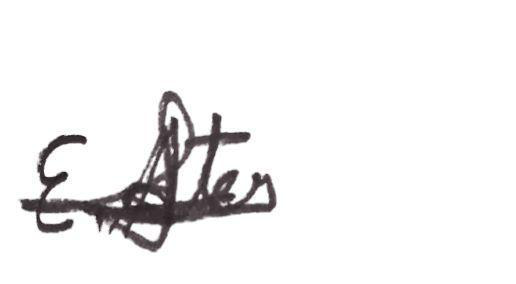
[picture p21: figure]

Efe Ateş | Program Manager | | 18.12.2025

# REVISIONS

Rev. No | Change Description | Date | QA Approval

TABLE OF CONTENTS

CHANGE RECORDS 2

FIRST RELEASE 2

REVISIONS 2

1. PURPOSE 4

2. SCOPE 4

3. ETHICAL DECLARATIONS 4

4. REFERENCES 4

# 1. PURPOSE

The purpose of this ethics declaration is to evaluate and address the ethical considerations associated with the design and development of a non-contact body temperature measurement device intended for users. The report aims to ensure that ethical principles such as user safety, privacy, accuracy, and respect for human dignity are upheld throughout the design process and potential use of the device.

# 2. SCOPE

The scope of this ethics declaration covers ethical aspects associated with the design, development, and intended clinical use of the non-contact thermometer. The device is designed to measure body temperature without physical contact, supporting hygienic practices in clinical environments. This report applies to the academic design phase of the project and does not include human testing or regulatory approval processes.

# 3. ETHICAL DECLARATIONS

The device adheres to the following medical standards. ISO 80601-2-56:2017: Medical electrical equipment – Particular requirements for basic safety and essential performance of clinical thermometers for body temperature measurement. It defines the accuracy requirements ±0.5℃ in the 34°C-42°C range and testing methods for infrared skin thermometers. IEC 60601-1 (General Safety): Medical electrical equipment – Part 1: General requirements for basic safety and essential performance. Ensuring the use of low-voltage (3.3V) DC power inherently complies with the safety limits for "Applied Parts." ISO 15223‐1:2016, Medical devices — Symbols to be used with medical device labels, labelling and information to be supplied — Part 1: General requirements

# 4. REFERENCES

[1] ”BS EN ISO 80601-2-56:2017+A1:2020 | 31 May 2020 | BSI Knowledge,” Bsigroup.com, May 31, 2020. https://knowledge.bsigroup.com/products/medical-electrical-equipment-particular-requirements-for-basic-safety-and-essential-performance-of-clinical-thermometers-for-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 (accessed Dec. 22, 2025).

‌

Doc. No: Part Number: 01-MIY-007 Ethics Declaration for Non-Contact Type Clinical Thermometer Rev:01 Page / ALL RIGHTS RESERVED. REPRODUCTION OR ISSUE TO THIRD PARTIES IN ANY FORM WHATEVER IS NOT PERMITTED WITHOUT WRITTEN AUTHORITY FROM THE PROPRIETORS.

ALL RIGHTS RESERVED. REPRODUCTION OR ISSUE TO THIRD PARTIES IN ANY FORM WHATEVER IS NOT PERMITTED WITHOUT WRITTEN AUTHORITY FROM THE PROPRIETORS.

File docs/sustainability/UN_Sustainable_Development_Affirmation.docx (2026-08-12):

Inserting image...

Faculty of Engineering

Department of Biomedical Engineering

# UN Sustainable Development Affirmation for The Non-Contact Clinical Thermometer

Part Number: 01-MIY-006

Rev-1

Date: 18/12/2025

## CHANGE RECORDS

FIRST RELEASE

CREATED BY
Name | Title | Date Sign.
Gülşen Demir | System Engineer | 18.12.2025


Augusta Nwosu | Electronics Engineer | 18.12.2025

CHECKED BY
Name | Title | Date Sign.
Fadime Taş | Quality Engineer | 18.12.2025

APPROVED BY
Name | Title | Date Sign.


Efe Ateş | Program Manager | 18.12.2025

REVISIONS

Rev. No | Change Description | Date | QA Approval

TABLE OF CONTENTS

CHANGE RECORDS 2

1. PURPOSE 4

2. SCOPE 4

3. SUSTAINABLE DEVELOPMENT 4

Alignment With Sustainable Engineering Practices 4

I. Design For Disassembly 4

II. Resource Efficiency 4

III. Economic Sustainability 5

IV. Environmental Sustainability 5

V. Social Sustainability 5

Alignment with the United Nations Sustainable Development Goals (SDGs) 5

SDG 3: Good Health and Well-Being 5

SDG 9: Industry, Innovation, and Infrastructure 6

SDG 12: Responsible Consumption and Production 6

SDG 13: Climate Action (Indirect Contribution) 6

Commitment to Sustainable and Ethical Design 7

REFERENCES 7

# 1. PURPOSE

The purpose of this affirmation is to demonstrate how the non-contact clinical thermometer project contributes to sustainable development, especially its alignment with the United Nations Sustainable Development Goals (SDGs). The project aims to support sustainable healthcare by improving hygienic clinical practices, enhancing patient safety, and promoting responsible use of medical resources through innovative, non-contact temperature measurement technology.

# 2. SCOPE

The scope of this affirmation covers the contribution of the non-contact clinical thermometer to sustainable development within healthcare systems. It focuses on the device’s role in supporting public health, reducing infection risks, minimizing medical waste, and encouraging sustainable medical device design. The affirmation applies to the academic design and development phase and does not include large-scale manufacturing or commercialization processes.

# 3. SUSTAINABLE DEVELOPMENT

The sustainable development section is expressed in two-fold. First, the alignment of the project with sustainable engineering practices is analysed. This explores how the project embodies the core philosophy of sustainable engineering by being extremely reusable. Next, the alignment of the project with the UN Sustainable Development Goals(SDGs) is analysed. Finally, its commitment to sustainable and ethical design is explored.

## Alignment With Sustainable Engineering Practices

### I. Design For Disassembly

Our device is highly repairable. Inculcating the use of headers and other connectors ensures their configurations are reusable in multiple devices. This extends the product lifecycle, keeping a majority of the material in use, should any part get damaged.

### II. Resource Efficiency

Our device was created with the mindset of maximizing our available resources. We prioritized selecting specific modules and subcomponents to perform the functions they are required. We also optimized our device by providing only the relevant materials, preventing excessive components that could be described as wastage.

### III. Economic Sustainability

Our device was created using COTS, which stands for Commercial-Off-The-Shelf components. These components are highly accessible on hobbyist platforms to encourage the replicability of the device. Our casing is also created using easily printable 3D designs.

### IV. Environmental Sustainability

Since most parts of our device are highly accessible, creating our device required no imports. We hit our target of creating an environmentally friendly device.

### V. Social Sustainability

Since this project was created by a team of highly cooperative individuals, every aspect of it was carried out with multiple contributors. This prevents intellectual waste as the knowledge of this process is being shared.

## Alignment with the United Nations Sustainable Development Goals (SDGs)

This project supports the United Nations Sustainable Development Goals by contributing to sustainable healthcare practices through the ethical design of a non-contact clinical thermometer. The device aligns with the following SDGs:

### SDG 3: Good Health and Well-Being

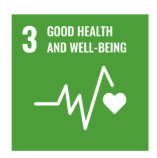
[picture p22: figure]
metin, yazı tipi, yeşil, logo içeren bir resim Yapay zeka tarafından oluşturulan içerik yanlış olabilir.

The non-contact clinical thermometer supports SDG 3 by enabling safe, hygienic, and rapid body temperature measurement in healthcare environments. Accurate temperature monitoring is essential for early detection of fever and effective patient assessment. The non-contact design reduces the risk of cross-infection, contributing to improved patient safety and overall public health outcomes.

### SDG 9: Industry, Innovation, and Infrastructure

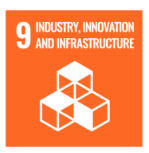
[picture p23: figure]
tasarım, metin, yazı tipi içeren bir resim Yapay zeka tarafından oluşturulan içerik yanlış olabilir.

The project promotes innovation in medical device design by integrating sensor technology and signal processing techniques to improve clinical measurement systems. The development of reliable, non-contact diagnostic tools contributes to strengthening healthcare infrastructure and encouraging technological advancement in the medical device industry.

### SDG 12: Responsible Consumption and Production

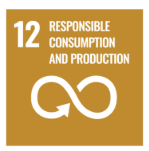
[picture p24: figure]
metin, yazı tipi, logo, grafik içeren bir resim Yapay zeka tarafından oluşturulan içerik yanlış olabilir.

The non-contact thermometer is designed with durability and efficient energy consumption in mind, reducing the need for disposable accessories and frequent replacements. This supports responsible use of resources and minimizes medical waste commonly associated with contact-based thermometers.

### SDG 13: Climate Action (Indirect Contribution)

By minimizing disposable components and promoting reusable medical equipment, the device indirectly contributes to reducing healthcare-related waste and environmental impact, supporting broader climate action goals.

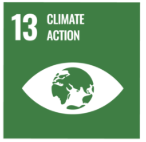
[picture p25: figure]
metin, logo, memeli, yazı tipi içeren bir resim Yapay zeka tarafından oluşturulan içerik yanlış olabilir.

## Commitment to Sustainable and Ethical Design

The project affirms a commitment to developing medical technologies that improve clinical efficiency while adhering to ethical standards, environmental responsibility, and global sustainability objectives. The design prioritizes patient safety, hygiene, and accuracy, supporting long-term sustainable healthcare practices.

# REFERENCES

  3.1. United Nations, Transforming Our World: The 2030 Agenda for Sustainable Development.
  3.2. United Nations, Sustainable Development Goal 3: Good Health and Well-Being.
  3.3. World Health Organization (WHO), Medical Device Design and Sustainable Healthcare.
  3.4. ISO 14971, Medical Devices — Application of Risk Management.

Doc. No: Part Number: 01-MIY-006 UN Sustainable Development Affirmation for Non-Contact Type Clinical Thermometer Rev:01 Page / ALL RIGHTS RESERVED. REPRODUCTION OR ISSUE TO THIRD PARTIES IN ANY FORM WHATEVER IS NOT PERMITTED WITHOUT WRITTEN AUTHORITY FROM THE PROPRIETORS.

ALL RIGHTS RESERVED. REPRODUCTION OR ISSUE TO THIRD PARTIES IN ANY FORM WHATEVER IS NOT PERMITTED WITHOUT WRITTEN AUTHORITY FROM THE PROPRIETORS.

MİKROELEKTRONİK, GÜDÜM VE ELEKTRO-OPTİK GRUBU MICROELECTRONICS, GUIDANCE AND ELECTRO-OPTICS DIVISION

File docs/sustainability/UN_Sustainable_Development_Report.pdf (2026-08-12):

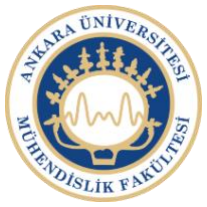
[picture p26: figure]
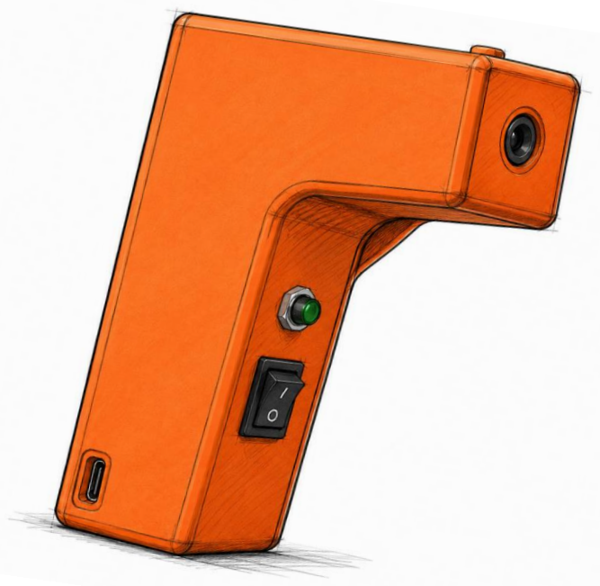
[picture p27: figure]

ALL RIGHTS RESERVED. REPRODUCTION OR ISSUE TO THIRD PARTIES IN ANY FORM WHATEVER IS NOT PERMITTED WITHOUT WRITTEN AUTHORITY FROM THE PROPRIETORS.

# Faculty of Engineering

# Department of Biomedical Engineering

# United Nations Sustainable Development Report for Non-Contact Type Clinical Thermometer

## PART NUMBER: 01-MIY-015

## REV: 2

## Date: 19/05/2026

Doc. No: Part
Number: 01-MIY-006

UN Sustainable Development Affirmation for Non-Contact Type Clinical Thermometer

Rev:01 | Page 2/6

ALL RIGHTS RESERVED. REPRODUCTION OR ISSUE TO THIRD PARTIES IN ANY FORM WHATEVER IS NOT PERMITTED WITHOUT WRITTEN AUTHORITY FROM THE PROPRIETORS.

### CHANGE RECORDS

FIRST RELEASE

CREATED BY
Name | Title | Date | Sign.
Efe Ateş | Program Engineer | 18.12.2025

CHECKED BY
Name | Title | Date | Sign.
Fadime Taş | Quality Engineer | 18.12.2025

APPROVED BY
Name | Title | Date | Sign.
Efe Ateş | Program Engineer | 18.12.2025

REVISIONS

Rev.
No

Change Description

Date QA Approval

Doc. No: Part
Number: 01-MIY-006

UN Sustainable Development Affirmation for Non-Contact Type Clinical Thermometer

Rev:01 | Page 3/6

TABLE OF CONTENTS

Doc. No: Part
Number: 01-MIY-006

UN Sustainable Development Affirmation for Non-Contact Type Clinical Thermometer

Rev:01 | Page 4/6

### 1. INTRODUCTION

Interpreting the Non-Contact Thermometer Project in Terms of Sustainable Development As biomedical engineering students, developing an adult non-contact thermometer has been a meaningful step toward understanding the UN's Sustainable Development Goals, particularly in the areas of responsible consumption, technological innovation, and health and well-being. Throughout this project, we made a conscious effort to align our work with several of these goals. To begin with, our thermometer supports UN SDG 3, which aims to ensure healthy lives and promote well-being for people of all ages, by offering a quick and non-contact method of measuring body temperature. Regarding SDG 9, which focuses on innovation and reliable infrastructure, we designed the infrared thermometer to serve as a dependable and efficient health monitoring tool. Our design prioritizes both accuracy and ease of use, allowing healthcare professionals to deliver better care with less effort while contributing to technological advancement in the medical field. We also worked toward making the device affordable and accessible, particularly for underserved communities, in order to help reduce health inequities. Additionally, by incorporating recyclable materials and energy-efficient technologies into our design, we promote responsible consumption and sustainable production practices that reduce environmental impact. In essence, our IR thermometer project supports global health, innovation, and sustainability by thoughtfully weaving multiple SDGs into a straightforward and practical design.

Alignment With Sustainable Engineering Practices

I. Design For Disassembly

Our device is highly repairable. Inculcating the use of headers and other connectors ensures their configurations are reusable in multiple devices. This extends the product lifecycle, keeping a majority of the material in use, should any part get damaged.

II. Resource Efficiency

Our device was created with the mindset of maximizing our available resources. We prioritized selecting specific modules and subcomponents to perform the functions they are required. We also optimized our device by providing only the relevant materials, preventing excessive components that could be described as wastage.

III. Economic Sustainability

Our device was created using COTS, which stands for Commercial-Off-The-Shelf components. These components are highly accessible on hobbyist platforms to encourage the replicability of the device. Our casing is also created using easily printable 3D designs.

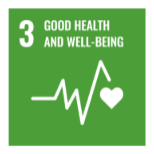
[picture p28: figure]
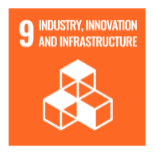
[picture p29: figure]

Doc. No: Part
Number: 01-MIY-006

UN Sustainable Development Affirmation for Non-Contact Type Clinical Thermometer

Rev:01 | Page 5/6
IV. | Environmental Sustainability

Since most parts of our device are highly accessible, creating our device required no imports. We hit our target of creating an environmentally friendly device.

V. Social Sustainability

Since this project was created by a team of highly cooperative individuals, every aspect of it was carried out with multiple contributors. This prevents intellectual waste as the knowledge of this process is being shared.

Alignment with the United Nations Sustainable Development Goals (SDGs)

This project supports the United Nations Sustainable Development Goals by contributing to sustainable healthcare practices through the ethical design of a non-contact clinical thermometer. The device aligns with the following SDGs:

SDG 3: Good Health and Well-Being

The non-contact clinical thermometer supports SDG 3 by enabling safe, hygienic, and rapid body temperature measurement in healthcare environments. Accurate temperature monitoring is essential for early detection of fever and effective patient assessment. The non-contact design reduces the risk of cross-infection, contributing to improved patient safety and overall public health outcomes.

SDG 9: Industry, Innovation, and Infrastructure

The project promotes innovation in medical device design by integrating sensor technology and signal processing techniques to improve clinical measurement systems. The development of reliable, non-contact diagnostic tools contributes to strengthening healthcare infrastructure and encouraging technological advancement in the medical device industry.

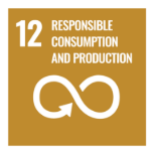
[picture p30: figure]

Doc. No: Part
Number: 01-MIY-006

UN Sustainable Development Affirmation for Non-Contact Type Clinical Thermometer

Rev:01 | Page 6/6

SDG 12: Responsible Consumption and Production

The non-contact thermometer is designed with durability and efficient energy consumption in mind, reducing the need for disposable accessories and frequent replacements. This supports responsible use of resources and minimizes medical waste commonly associated with contact-based thermometers.

SDG 13: Climate Action (Indirect Contribution)

By minimizing disposable components and promoting reusable medical equipment, the device indirectly contributes to reducing healthcare-related waste and environmental impact, supporting broader climate action goals.

Commitment to Sustainable and Ethical Design
The project affirms a commitment to developing medical technologies that improve clinical efficiency while adhering to ethical standards, environmental responsibility, and global sustainability objectives. The design prioritizes patient safety, hygiene, and accuracy, supporting long-term sustainable healthcare practices.

### REFERENCES

1.1. United Nations, Transforming Our World: The 2030 Agenda for Sustainable Development.
1.2. United Nations, Sustainable Development Goal 3: Good Health and Well-Being.
1.3. World Health Organization (WHO), Medical Device Design and Sustainable Healthcare.
1.4. ISO 14971, Medical Devices — Application of Risk Management.

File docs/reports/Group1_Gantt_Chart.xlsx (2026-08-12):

TASK | RESPONSIBILITY | START | END | Sept | October |  |  |  |  | November |  |  |  | December |  |  |  | January |  |  |  |  | February |  |  |  | March |  |  |  | April |  |  |  |  | May |  |  |  | June
 |  |  |  | 39 | 40 | 41 | 42 | 43 | 44 | 45 | 46 | 47 | 48 | 49 | 50 | 51 | 52 | 1 | 2 | 3 | 4 | 5 | 6 | 7 | 8 | 9 | 10 | 11 | 12 | 13 | 14 | 15 | 16 | 17 | 18 | 19 | 20 | 21 | 22 | 23 | 24 | 25 | 26
Week number |  |  |  | 1 | 2 | 3 | 4 | 5 | 6 | 7 | 8 | 9 | 10 | 11 | 12 | 13 | 14 | 15 | 16 | 17 | 18 | 19 | 20 | 21 | 22 | 23 | 24 | 25 | 26 | 27 | 28 | 29 | 30 | 31 | 32 | 33 | 34 | 35 | 36 | 37 | 38 | 39 | 40
Project Management Plan (PMP) | Program Engineer | 13 10 2025 | 20 11 2025
Requirements capture | System Engineer | 2025-10-25 | 2025-10-30
Conceptual Design | Everyone | 13 10 2025 | 2025-11-07
Design Description | System Engineer | 2025-10-25 | 2025-11-07
Configuration Item List | System Engineer | 2025-10-25 | 2025-11-07
Preliminary Design Review (PDR) | Program Engineer | 2025-11-01 | 2025-11-23
Detailed Design |  | 2025-11-23 | 2026-01-07
Electronic Design (CAD/CAM, Assembly Drawings) | Electronics Engineer | 2025-11-23 | 2026-12-27
Mechanical Design (CAD/CAM) | Mechanical Enginer | 2025-11-23 | 2026-12-27
Software design, test, document | Software Engineer | 2025-11-23 | 2026-12-27
Purchasing | Electronics Engineer | 2025-11-23 | 2026-12-27
Critical Design Review | Program Engineer | 2025-12-27 | 2026-01-07
Implementation (Prototype Production, V2T) |  | 2026-01-05 | 2026-03-29
3D Printing | Mechanical Engineer | 2026-01-05 | 2026-03-05
PCB Assembly, Wiring Assembly production, ICT, Fabtest, Marking) | Production Engineer | 2026-01-01 | 2026-03-05
Workmanship Inspection, NCR | QA Engineer | 2026-01-19 | 2026-03-05
Software test, finalizing software | Software Engineer | 2026-01-19 | 2026-03-05
Thermometer Assembly drawing | System Engineer | 2026-02-02 | 2026-03-05
Top assembly production | Mechanical Engineer | 2026-02-16 | 2026-03-05
Acceptance Test Procedure (ATP) | QA Engineer | 2026-02-02 | 2026-03-14
Test setup | System Engineer | 2026-02-02 | 2026-03-14
Acceptance Test | Group Task | 2026-02-02 | 2026-03-14
Verification/Validation Test Plan | QA Engineer | 2026-02-16 | 2026-03-01
Verification/Validation Test Procedure | Software Engineer | 2026-03-01 | 2026-03-14
Verification/Validation Tests | Group Task | 2026-03-14 | 2026-03-28
Implementation Review | Alper Demirhan | 2026-04-01 | 2026-04-10
Supporting Processes |  | 2025-11-03 | 2026-05-25
Quality Assurance (Audit, CA, NCR, V2T plan, ATP) | QA Engineer | 2025-10-29 | 2026-03-14
Configuration Management | System Engineer | 2025-10-29 | 2026-04-10
Risk Management | Program Engineer | 2025-11-17 | 2025-11-23
Procurement (purchasing) | Electronics Engineer | 2025-11-24 | 2026-03-14
Monthly Reports | Program Engineer | 2025-11-24 | 2026-05-25

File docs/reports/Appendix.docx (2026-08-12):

# APPENDIX I


Figure AI.1 Weight of Designed Non-Contact Clinical Thermometer


Figure AI.2 Non-Contact Clinical Thermometer designed by Group 1 in 2026

Doc. No: Part Number: 01-MIY-016 UN Sustainable Development Affirmation for Non-Contact Type Clinical Thermometer Rev:01 Page / ALL RIGHTS RESERVED. REPRODUCTION OR ISSUE TO THIRD PARTIES IN ANY FORM WHATEVER IS NOT PERMITTED WITHOUT WRITTEN AUTHORITY FROM THE PROPRIETORS.

ALL RIGHTS RESERVED. REPRODUCTION OR ISSUE TO THIRD PARTIES IN ANY FORM WHATEVER IS NOT PERMITTED WITHOUT WRITTEN AUTHORITY FROM THE PROPRIETORS.

MİKROELEKTRONİK, GÜDÜM VE ELEKTRO-OPTİK GRUBU MICROELECTRONICS, GUIDANCE AND ELECTRO-OPTICS DIVISION

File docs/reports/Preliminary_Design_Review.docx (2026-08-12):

Inserting image...

Faculty of Engineering

Department of Biomedical Engineering

# Preliminary Design Review (PMR)

# for Clinical Body Thermometer

Part Number: 01-MIY-005

Rev-1

Date: 10/12/2025

# CHANGE RECORDS

## FIRST RELEASE

CREATED BY
Name | Title | Date Sign.
Gülşen Demir | System Engineer | 10.12.2025

CHECKED BY
Name | Title | Date Sign.


Efe Ateş | Program Manager | 10.12.2025
Eren Can Kayabaşı | Software Engineer | 10.12.2025
Furkan Bacak | Production Engineer | 10.12.2025
Fadime Taş | Quality Engineer | 10.12.2025
Augusta Nwosu | Electrical Engineer | 10.12.2025
Ayşe Sarıkaya | Mechanical Engineer | 10.12.2025

TABLE OF CONTENTS

CHANGE RECORDS 2

FIRST RELEASE 2

1. PURPOSE 4

2. SCOPE 4

3. RESPONSIBILITY 4

4. REFERENCES 4

5. CHECK LIST FOR PRELIMINARY DESIGN REVIEW 5

6. APPROVALS 5

# 1. PURPOSE

According to the Project Management Plan, this document will confirm that the initial design work is completed and ready to proceed the detailed design.

# 2. SCOPE

The scope of the design activities leading to the Preliminary Design Review includes to formally verify that the proposed design approach is sound and that all necessary foundational design documents are completed using a check list, thereby enabling the project to formally proceed to the resource-intensive detailed design and specification phase.

# 3. RESPONSIBILITY

Program Engineer is responsible, scheduling, organizing. System Engineer makes available the design data and report the design review. Quality Engineer is responsible for analysing the reports and make corrective actions.

# 4. REFERENCES

4.1. Project Management Plan

4.2. System Requirements Specification

4.3. Design Description Document

4.4. Configuration Item List

# 5. CHECK LIST FOR PRELIMINARY DESIGN REVIEW

Item No | Task Description | Status | C/A
1 | System Requirement Specification is prepared and approved by QA | OK
2 | Each requirement is unambiguous, verifiable and is not conflict with other requirements | OK
3 | Applicable standards and guidance are considered | OK
4 | All requirements are correctly defined | OK
5 | Environmental requirements are defined | OK
6 | Safety requirements are defined | OK
7 | Design Description Document is prepared and approved by QA | OK
8 | The design should be capable of being implemented, tested and maintained | OK
9 | All hardware functions and interfaces are covered | OK
10 | Architecture is covered completely | OK
11 | Configuration items are shown in a block diagram | OK
12 | Configuration Item List document prepared and approved by QA | OK
13 | Each configuration item has a specific part number for identification | OK
14 | The components to be used in the design are not obsolete | OK

Status: OK (Okey) or NOK (Not Okey)

If the status is NOK then Corrective Action Due Date will be written

C/A:

# 6. APPROVALS

Efe Ateş - Program Engineer

Gülşen Demir - System Engineer

Augusta Nwosu - Electronics Engineer

Ayşe Sarıkaya - Mechanical Engineer

Fadime Taş - QA Engineer

Eren Can Kayabaşı - Software Engineer

Furkan Bacak - Production Engineer

Doc. No: 11-MIY-004 Preliminary Design Review (PMR) for Clinical Body Thermometer Rev:01 Page /5 ALL RIGHTS RESERVED. REPRODUCTION OR ISSUE TO THIRD PARTIES IN ANY FORM WHATEVER IS NOT PERMITTED WITHOUT WRITTEN AUTHORITY FROM THE PROPRIETORS.

ALL RIGHTS RESERVED. REPRODUCTION OR ISSUE TO THIRD PARTIES IN ANY FORM WHATEVER IS NOT PERMITTED WITHOUT WRITTEN AUTHORITY FROM THE PROPRIETORS.

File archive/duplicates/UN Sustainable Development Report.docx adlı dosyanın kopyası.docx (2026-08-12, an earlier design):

Inserting image...

Faculty of Engineering

Department of Biomedical Engineering

United Nations Sustainable Development Report for Non-Contact Type Clinical Thermometer

PART NUMBER: 01-MIY-015

REV: 2

Date: 19/05/2026

alet, portakal, turuncu içeren bir resim Yapay zeka tarafından oluşturulmuş içerik yanlış olabilir.

## CHANGE RECORDS

FIRST RELEASE

CREATED BY
Name | Title | Date Sign.
Efe Ateş | Program Engineer | 19.05.2026

CHECKED BY
Name | Title | Date Sign.
Fadime Taş | Quality Engineer | 19.05.2026

APPROVED BY
Name | Title | Date Sign.


Efe Ateş | Program Engineer | 19.05.2026

REVISIONS

Rev. No | Change Description | Date | QA Approval
2 | Brief description about UN Sustainable Goals Added | 19.05.2026

TABLE OF CONTENTS

CHANGE RECORDS 2

1. INTRODUCTION 4

Alignment With Sustainable Engineering Practices 4

I. Design For Disassembly 4

II. Resource Efficiency 4

III. Economic Sustainability 4

IV. Environmental Sustainability 5

V. Social Sustainability 5

Alignment with the United Nations Sustainable Development Goals (SDGs) 5

SDG 3: Good Health and Well-Being 5

SDG 9: Industry, Innovation, and Infrastructure 5

SDG 12: Responsible Consumption and Production 6

SDG 13: Climate Action (Indirect Contribution) 6

Commitment to Sustainable and Ethical Design 6

REFERENCES 6

# 1. INTRODUCTION

Interpreting the Non-Contact Thermometer Project in Terms of Sustainable Development As biomedical engineering students, developing an adult non-contact thermometer has been a meaningful step toward understanding the UN's Sustainable Development Goals, particularly in the areas of responsible consumption, technological innovation, and health and well-being. Throughout this project, we made a conscious effort to align our work with several of these goals. To begin with, our thermometer supports UN SDG 3, which aims to ensure healthy lives and promote well-being for people of all ages, by offering a quick and non-contact method of measuring body temperature. Regarding SDG 9, which focuses on innovation and reliable infrastructure, we designed the infrared thermometer to serve as a dependable and efficient health monitoring tool. Our design prioritizes both accuracy and ease of use, allowing healthcare professionals to deliver better care with less effort while contributing to technological advancement in the medical field. We also worked toward making the device affordable and accessible, particularly for underserved communities, in order to help reduce health inequities. Additionally, by incorporating recyclable materials and energy-efficient technologies into our design, we promote responsible consumption and sustainable production practices that reduce environmental impact. In essence, our IR thermometer project supports global health, innovation, and sustainability by thoughtfully weaving multiple SDGs into a straightforward and practical design.

## Alignment With Sustainable Engineering Practices

### I. Design For Disassembly

Our device is highly repairable. Inculcating the use of headers and other connectors ensures their configurations are reusable in multiple devices. This extends the product lifecycle, keeping a majority of the material in use, should any part get damaged.

### II. Resource Efficiency

Our device was created with the mindset of maximizing our available resources. We prioritized selecting specific modules and subcomponents to perform the functions they are required. We also optimized our device by providing only the relevant materials, preventing excessive components that could be described as wastage.

### III. Economic Sustainability

Our device was created using COTS, which stands for Commercial-Off-The-Shelf components. These components are highly accessible on hobbyist platforms to encourage the replicability of the device. Our casing is also created using easily printable 3D designs.

### IV. Environmental Sustainability

Since most parts of our device are highly accessible, creating our device required no imports. We hit our target of creating an environmentally friendly device.

### V. Social Sustainability

Since this project was created by a team of highly cooperative individuals, every aspect of it was carried out with multiple contributors. This prevents intellectual waste as the knowledge of this process is being shared.

## Alignment with the United Nations Sustainable Development Goals (SDGs)

This project supports the United Nations Sustainable Development Goals by contributing to sustainable healthcare practices through the ethical design of a non-contact clinical thermometer. The device aligns with the following SDGs:

### SDG 3: Good Health and Well-Being

metin, yazı tipi, yeşil, logo içeren bir resim Yapay zeka tarafından oluşturulan içerik yanlış olabilir.

The non-contact clinical thermometer supports SDG 3 by enabling safe, hygienic, and rapid body temperature measurement in healthcare environments. Accurate temperature monitoring is essential for early detection of fever and effective patient assessment. The non-contact design reduces the risk of cross-infection, contributing to improved patient safety and overall public health outcomes.

### SDG 9: Industry, Innovation, and Infrastructure

tasarım, metin, yazı tipi içeren bir resim Yapay zeka tarafından oluşturulan içerik yanlış olabilir.

The project promotes innovation in medical device design by integrating sensor technology and signal processing techniques to improve clinical measurement systems. The development of reliable, non-contact diagnostic tools contributes to strengthening healthcare infrastructure and encouraging technological advancement in the medical device industry.

### SDG 12: Responsible Consumption and Production

metin, yazı tipi, logo, grafik içeren bir resim Yapay zeka tarafından oluşturulan içerik yanlış olabilir.

The non-contact thermometer is designed with durability and efficient energy consumption in mind, reducing the need for disposable accessories and frequent replacements. This supports responsible use of resources and minimizes medical waste commonly associated with contact-based thermometers.

### SDG 13: Climate Action (Indirect Contribution)

By minimizing disposable components and promoting reusable medical equipment, the device indirectly contributes to reducing healthcare-related waste and environmental impact, supporting broader climate action goals.

metin, logo, memeli, yazı tipi içeren bir resim Yapay zeka tarafından oluşturulan içerik yanlış olabilir.

## Commitment to Sustainable and Ethical Design

The project affirms a commitment to developing medical technologies that improve clinical efficiency while adhering to ethical standards, environmental responsibility, and global sustainability objectives. The design prioritizes patient safety, hygiene, and accuracy, supporting long-term sustainable healthcare practices.

# REFERENCES

  1.1. United Nations, Transforming Our World: The 2030 Agenda for Sustainable Development.
  1.2. United Nations, Sustainable Development Goal 3: Good Health and Well-Being.
  1.3. World Health Organization (WHO), Medical Device Design and Sustainable Healthcare.
  1.4. ISO 14971, Medical Devices — Application of Risk Management.

Doc. No: Part Number: 01-MIY-015 UN Sustainable Development Affirmation for Non-Contact Type Clinical Thermometer Rev:01 Page / ALL RIGHTS RESERVED. REPRODUCTION OR ISSUE TO THIRD PARTIES IN ANY FORM WHATEVER IS NOT PERMITTED WITHOUT WRITTEN AUTHORITY FROM THE PROPRIETORS.

ALL RIGHTS RESERVED. REPRODUCTION OR ISSUE TO THIRD PARTIES IN ANY FORM WHATEVER IS NOT PERMITTED WITHOUT WRITTEN AUTHORITY FROM THE PROPRIETORS.

MİKROELEKTRONİK, GÜDÜM VE ELEKTRO-OPTİK GRUBU MICROELECTRONICS, GUIDANCE AND ELECTRO-OPTICS DIVISION

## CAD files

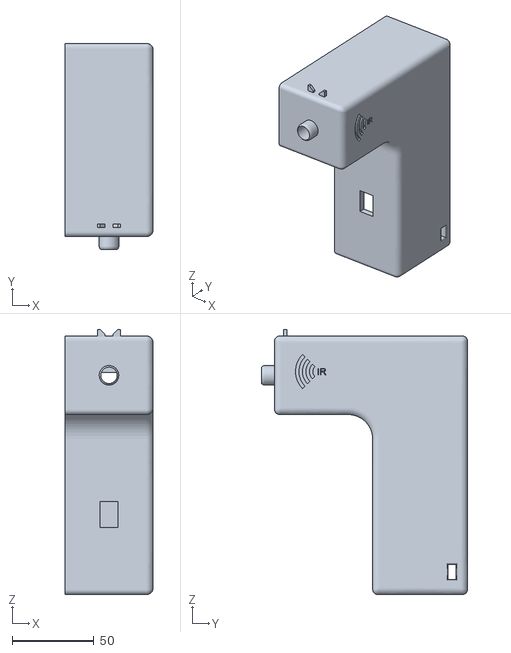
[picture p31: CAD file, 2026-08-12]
mechanical/Thermometer-Refined-body.stl
54.0 x 126.0 x 162.0

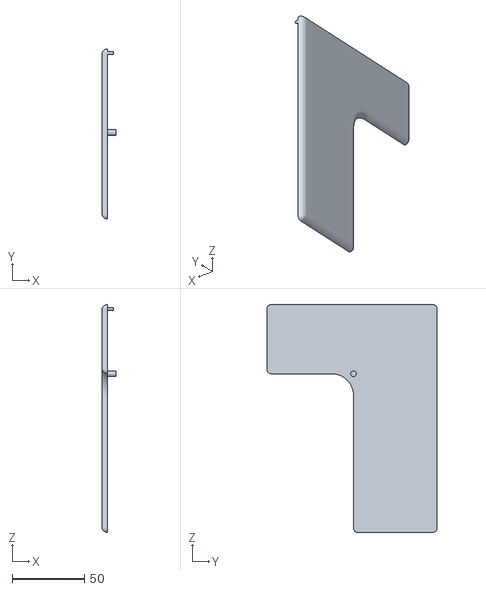
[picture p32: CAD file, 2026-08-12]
mechanical/Thermometer-Refined-Cover.stl
10.0 x 118.0 x 158.0

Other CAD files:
mechanical/Fusion360ModelofIRClinicalThermo.f3z

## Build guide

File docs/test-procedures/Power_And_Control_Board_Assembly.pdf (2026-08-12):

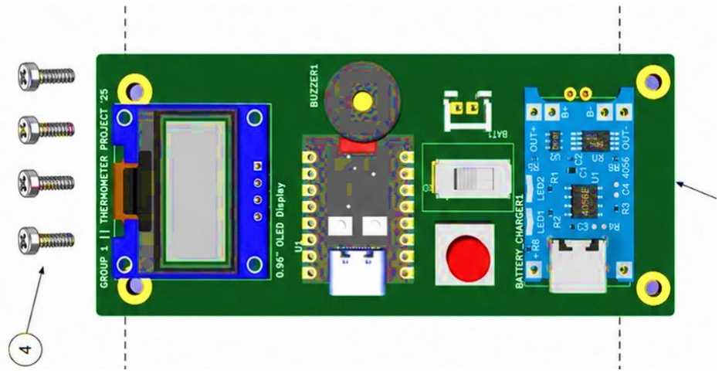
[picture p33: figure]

ALL RIGHTS RESERVED. REPRODUCTION OR ISSUE TO THIRD PARTIES IN ANY FORM WHATEVER IS NOT PERMITTED WITHOUT WRITTEN AUTHORITY FROM THE PROPRIETORS.

# Faculty of Engineering

# Department of Biomedical Engineering

# Non-Contact Type Clinical Thermometer Power

# And Control Board Assembly

## PART NUMBER:001-MIY-009

## REV:1

## DATE:17.05.2026

Doc. No: 001-MIY-009 Non - Contact Thermometer Power and Control Board
Assembly

Rev1 Page 2/6

ALL RIGHTS RESERVED. REPRODUCTION OR ISSUE TO THIRD PARTIES IN ANY FORM WHATEVER IS NOT PERMITTED WITHOUT WRITTEN AUTHORITY FROM THE PROPRIETORS.

### CHANGE RECORDS

FIRST RELEASE

CREATED BY

Name | Title | Date | Sign.
Gülşen Demir | System Engineer | 17.05.2026

CHECKED BY

Name | Title | Date | Sign.
Fadime Taş | Quality Engineer
| | 17.05.2026
APPROVED BY
Name | Title | Date | Sign.
Efe Ateş | Program Engineer | 17.05.2026

REVISIONS

Rev. No Change Description | Date | QA Approval

Doc. No: 001-MIY-009 | Non - Contact Thermometer Power and Control Board
Rev1 | Page 3/6

### TABLE OF CONTENTS

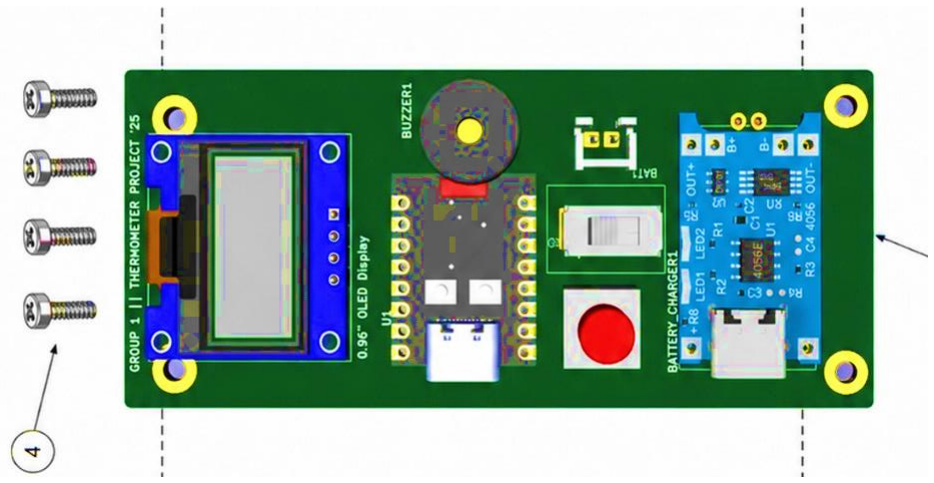
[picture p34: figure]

Doc. No: 001-MIY-009 | Non - Contact Thermometer Power and Control Board
Rev1 | Page 4/6

### 1. DRAWINGS

### 1.1 COMPONENTS LOCATIONS

Figure1:PCB Model

### 1.2 ELECTRICAL INTERFACE

Item | P/N | Description | Location | Qty
1 | KIT-1 | ESP32-C3 Zero Mini MCU Board | Center | 1
2 | DISP-1 | 0.96" OLED Display Module | Left side | 1
3 | BZ-1 | Buzzer | Top center | 1
4 | SW-1 | Slide Power Switch | Center-right | 1
5 | PB-1 | Push Button Switch | Lower center-right | 1
6 | KIT-3 | TP4056 Battery Charger Module | Right side | 1
7 | BAT-1 | Battery Connector / Input | Near TP4056 module | 1
8 | PCB-1 | Main Printed Circuit Board | Base board | 1
9 | H1 | Mounting Hole | Top-left corner | 1
10 | H2 | Mounting Hole | Bottom-left corner | 1
11 | H3 | Mounting Hole | Top-right corner | 1
12 | H4 | Mounting Hole | Bottom-right corner | 1
13 | SCR-1 | Mounting Screws | Left side assembly | 4

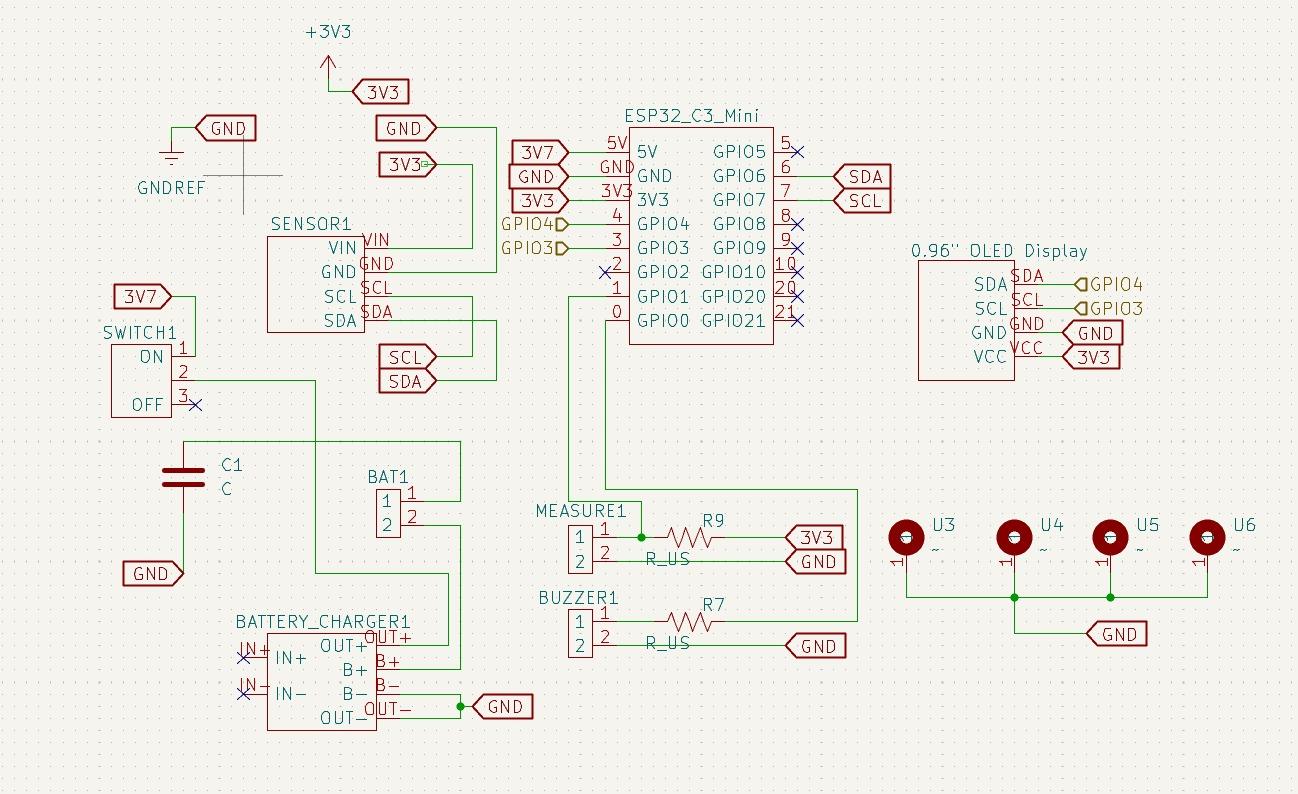
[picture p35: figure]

Doc. No: 001-MIY-009 | Non - Contact Thermometer Power and Control Board
Rev1 | Page 5/6

1.3 CIRCUIT DIAGRAM

Figure 2: Circuit Diagram Schematic

### 2. PART LIST (BILL OF MATERIAL-BOM)

Item | P/N | Description | Location | Quantity
1 | 01-PRT-001 | MCU Kit, ESP32 C3 Mini | ESP32_C3_Mini | 1
2 | 01-PRT-002 | MLX90614, Infrared Camera Sensor | SENSOR1 | 1
3 | 01-PRT-003 | TP4056, Battery Charger Module | BATTERY_CHARGER1 | 1
4 | 01-PRT-004 | Display Kit, 0.96" LCD Display | 0.96" OLED Display | 1
5 | 01-PRT-005 | On /Off Slider Switch | SWITCH1 | 1
6 | 01-PRT-006 | Measurement Button | MEASURE1 | 1
7 | 01-PRT-007 | Buzzer | BUZZER1 | 1

Doc. No: 001-MIY-009 | Non - Contact Thermometer Power and Control Board
Rev1 | Page 6/6
Item | P/N | Description | Location | Quantity
8 | 01-PRT-008 | Resistor | R7, R9 | 2
9 | 01-PRT-009 | JST Connector | BAT1 | 1
10 | 01-PRT-010 | Lithium Ion Battery | Connects to BAT1 | 1
11 | 01-PRT-011 | Sensor PCB | System Assembly | 1
12 | 01-PRT-012 | Housing Assembly | System Assembly | 1

### 3. TECHNICAL DESCRIPTIONS

3.1. Soldering shall be done according to the latest revision of IPC-J-STD-001 and inspected per IPC-A-610. Clean the solder joints with Isopropyl Alcohol and a brush before inspection.
3.2. The first component to be installed is the Battery Charger Module (BATTERY_CHARGER1 / TP4056) and the battery connector (BAT1). After installation, connect the rechargeable Li-Po battery to BAT1 and provide 5V power via the USB-C input on the charger module. Measure the voltage across the OUT+ and OUT- terminals to verify battery output. It should be between 3.7 VDC and 4.2 VDC. Remove the battery and USB power connections.

### 3.3. Solder the remaining surface mount components (resistors R7, R9, capacitor C1), the

switch (SWITCH1), the measurement button (MEASURE1), the buzzer (BUZZER1), the infrared sensor (SENSOR1), and the MCU Kit (ESP32_C3_Mini). Perform a continuity check to ensure there are no short circuits or open circuits, paying special attention to the 3V3 and GND lines.

3.4. Insert the battery and toggle SWITCH1 to the ON position to verify system power. Measure the voltage at the 3V3 pin on the ESP32-C3 Mini (relative to GND). It should be 3.3V ± 0.2V.

### 3.5. Solder the 0.96" OLED Display. Power the system on again and verify that the display

illuminates properly without dropping the 3V3 line voltage.

3.6. Connect the ESP32 C3 Mini directly to a computer via its integrated USB port to upload the firmware. Once the firmware is flashed, disconnect the device from the PC; the device operates entirely on battery power and requires no PC data acquisition or external DC power supplies for the functional testing phases.

### 3.7. Trigger the MEASURE1 button and observe the non-contact temperature readings for

ambient and object temperatures on the OLED display. Verify that the visual interface responds accurately according to the programmed OLED indicators, ensuring it operates correctly without displaying arbitrary strings such as "BELOW THE RANGE" or "ABOVE THE RANGE".

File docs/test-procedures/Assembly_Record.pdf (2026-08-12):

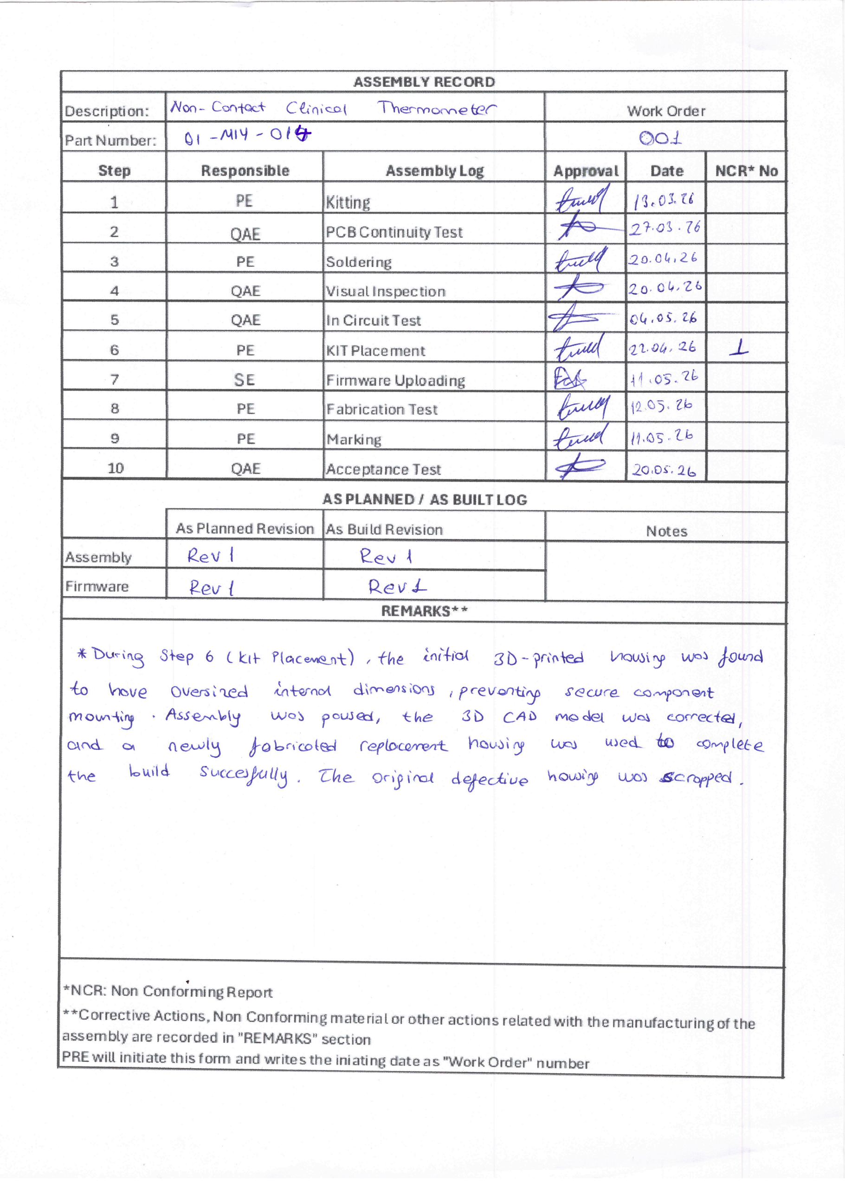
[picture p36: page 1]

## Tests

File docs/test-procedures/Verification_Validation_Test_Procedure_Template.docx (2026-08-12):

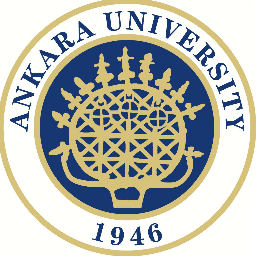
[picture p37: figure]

Verification/Validation Test Procedure (V2TP)

for Contact Thermometer

Part Number: 20-TRM-930

Rev: 1

Date: 23 April 2024

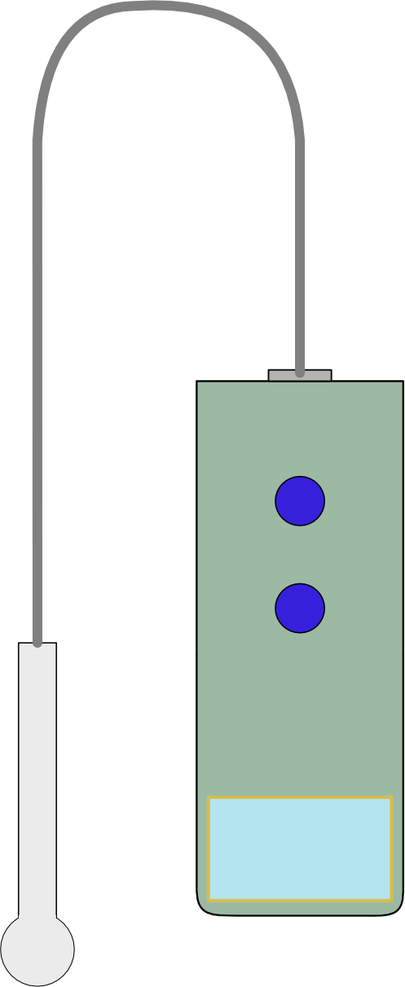
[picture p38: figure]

# change records

## fırst release

CREATED BY
Name | Title | Date Sign.
| Program Eng

CHECKED BY
Name | Title | Date Sign.
| Quality Eng

APPROVED BY
Name | Title | Date Sign.
| System Eng

## REVISIONS

Rev. No | Change Description | Date | QA Approval

TABLE OF CONTENTS

change records 2

fırst release 2

REVISIONS 2

1. scope 4

2. REFERENCES 4

3. verification tests 4

3.1. functıonal tests 4

3.2. weıght 4

3.3. surface 4

3.4. operatıng temperature 5

3.5. storage temperature 5

3.6. display sıze 5

3.7. measurıng sıte 5

3.8. power supply 5

4. valıdation tests 6

4.1. accuracy tests 6

5. test report 6

Attachment-1: verıfıcatıon/valıdatıon Test Data Sheet 7

# 1. scope

VALIDATION is the confirmation that the requirements of a contact clinical thermometer have been fulfilled through clinical tests on actual subjects (patients), using statistical methods where the VERIFICATION is the confirmation that the requirements of clinical thermometer have been fulfilled through laboratory tests using a reference temperature source.

For a CONTACT CLINICAL THERMOMETER that operates in the ADJUSTED MODE, the LABORATORY ACCURACY is VERIFIED in a DIRECT MODE and the CLINICAL ACCURACY is VALIDATED in the ADJUSTED MODE (OPERATING MODE) with a sufficiently large group of human subjects.

# 2. REFERENCES

  2.1. ISO 80601-2-56:2017 : Part 2-56: Particular requirements for basic safety and essential performance of clinical thermometers for body temperature measurement
  2.2. 20-TRM-800: System Requirement Specification, Contact Body Thermometer
  2.3. 20-TRM-830: Verification-Validation Test Plan for Contact Body Thermometer
  2.4. 20-TRM-900: Acceptance Test Procedure

# 3. verification tests

Most of the requirements which must be verified within the context of verification tests are covered by Acceptance Test Procedure. So, the first step for the verification tests is to perform a acceptance test. After successful completion of acceptance test, remaining tests, inspections and demonstration given in Verification/Validation matrix will be performed.

# 3.1. functıonal tests

Run the acceptance tests as per 20-TRM-900, Acceptance Test Procedure and record the results in Verification/Validation Test Data Sheet given in attachment-1.

# 3.2. weıght

Measure the weight of thermometer including its probe with a precision calibrated scale to verify its weight is less than the specified requirement of 200gr.

# 3.3. surface

Demonstrate that there is no malfunction, no damage or color changes after cleaning the thermometer with a IPA alcohol.

# 3.4. operatıng temperature

Operating temperature test is not applicable for this project, since necessary temperature chamber is not available.

# 3.5. storage temperature

Storage temperature test is not applicable for this project, since necessary temperature chamber is not available.

# 3.6. display sıze

The temperature reading on the screen will be measured with a scale to verify that the characters at least 4mm height and readable.

# 3.7. measurıng sıte

Demonstrate that the sensor tip can be easily put into the armpit.

# 3.8. power supply

1. Remove the top cover of the thermometer.
2. Plug the USB-C connector of 5VDC adaptor to the charge input of thermometer.
3. Observe that the red LED of charger module is turned on showing the charging mode.
4. After sufficient time the blue LED pf charger module will be turned on to show the charge is completed.
5. Unplug the 5VDC adapter and verify that the thermometer can be operated with its battery.

# 4. valıdation tests

The CLINICAL ACCURACY of an ADJUSTED MODE CLINICAL THERMOMETER is required to be additionally VALIDATED with actual subjects (PATIENTS). Since all subjects are different, statistical methods are employed to compare the OUTPUT TEMPERATURES of the CLINICAL THERMOMETER under test (DUT) for the REFERENCE BODY SITE with those of a REFERENCE CLINICAL THERMOMETER (RCT) whose OUTPUT TEMPERATURES represent the same REFERENCE BODY SITE as the DUT.

In the scope of validation tests, the CLINICAL BIAS, Δcb, with its LIMITS OF AGREEMENT, LA, the CLINICAL REPEATABILITY, σr, the REFERENCE BODY SITE and MEASURING SITE for each OPERATING MODE shall be measured.

# 4.1. clınıcal accuracy tests

The methods, procedures and the calculations shall be performed in accordance with ISO 80601-2-56:2017: Part 2-56, paragraph 201.102 (CLINICAL ACCURACY VALIDATION).

the results for clinical bias, Δcb, with its limits of agreement, LA, the clinical repeatability, σr shall be documented verification/validation test data sheet given in attachment-1.

# 5. test report

1. Test results will be recorded on the Acceptance Test Data Sheet in the Attachment-1

# Attachment-1: verıfıcatıon/valıdatıon Test Data Sheet

| VERIFICATION/VALIDATION TEST DATA SHEET
Assembly P/N: | | Date:
Assembly S/N: | | Test Operator:
Test Procedure: | | QA
ATP paragraph | Description | Test Limits | Measurement Result | Pass/Fail
ATP para 4.1 | Operating Controls | N/A
ATP para 4.1.1 | MODE switch | Toggle the mode
ATP para 4.1.2 | POWER ON/OFF | Display Temperature
ATP para 4.1.2 | Automatic Turn Off | Turn off time < 30 sec
ATP para 4.2 | Accuracy | < 0.3°C
ATP para 4.3 | Rated Output Range | 34 °C < T < 43°C
ATP para 4.4 | Units of Measure | °C
ATP para 4.5 | Measurement Time | < 30 sec
ATP para 4.6 | Alarm Conditions | N/A
ATP para 4.6.1 | Completion of measurement | Sound alarm
ATP para 4.6.2 | Below The Tange | Blue Display
ATP para 4.6.2 | Above The Range | Red Display
V2TP para 3.2 | Weight | <200gr
V2TP para 3.3 | Surface | Demonstrate
V2TP para 3.4 | Operating Temperature | N/A
V2TP para 3.5 | Storage Temperature | N/A
V2TP para 3.6 | Display Size | > = 4 mm
V2TP para 3.7 | Measuruing Site | Demonstrate
V2TP para 3.8 | Power Supply | Rechargable
V2TP para 4.1 | Clinical Bias, Δcb
V2TP para 4.1 | Limits of Agreement, LA
V2TP para 4.1 | Clinical Repeatability, σr
| | Completion Date:

N/A: Not Applicable

Doc. No: 20-TRM-930 V2TP for Contact Thermometer Rev1 Page / ALL RIGHTS RESERVED. REPRODUCTION OR ISSUE TO THIRD PARTIES IN ANY FORM WHATEVER IS NOT PERMITTED WITHOUT WRITTEN AUTHORITY FROM THE PROPRIETORS.

ALL RIGHTS RESERVED. REPRODUCTION OR ISSUE TO THIRD PARTIES IN ANY FORM WHATEVER IS NOT PERMITTED WITHOUT WRITTEN AUTHORITY FROM THE PROPRIETORS.

MİKROELEKTRONİK, GÜDÜM VE ELEKTRO-OPTİK GRUBU MICROELECTRONICS, GUIDANCE AND ELECTRO-OPTICS DIVISION

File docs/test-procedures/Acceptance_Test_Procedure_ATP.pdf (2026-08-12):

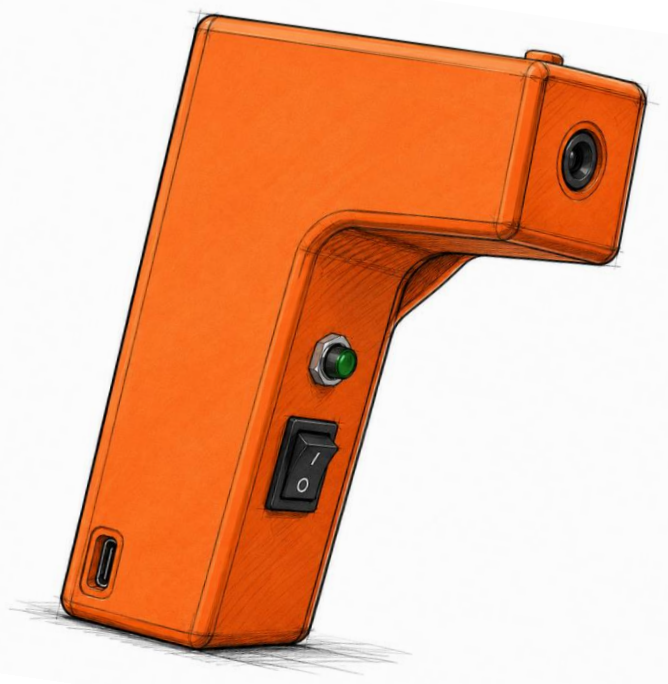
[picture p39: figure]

### ALL RIGHTS RESERVED. REPRODUCTION OR ISSUE TO THIRD PARTIES IN ANY FORM

WHATEVER IS NOT PERMITTED WITHOUT WRITTEN AUTHORITY FROM THE PROPRIETORS.

# Faculty of Engineering

# Department of Biomedical Engineering

# Non-Contact Type Clinical Thermometer Acceptance Test Procedure

# PART NUMBER: 01-MIY-011

# REV: 1

# DATE:16.05.2026

Doc.No: 01-MIY-011 | Non - Contact Thermometer Acceptance Test Procedure | Rev1 | Page 2/14

ALL RIGHTS RESERVED. REPRODUCTION OR ISSUE TO THIRD PARTIES IN ANY FORM WHATEVER IS NOT PERMITTED WITHOUT WRITTEN AUTHORITY FROM THE PROPRIETORS.

## CHANGE RECORDS

### FIRST RELEASE

CREATED BY

Name | Title | Date | Sign.
Gülşen Demir | System Engineer | 16.05.2026

CHECKED BY

Name | Title | Date | Sign.
Fadime Taş | Quality Engineer
| | 16.05.2026
APPROVED BY
Name | Title | Date | Sign.
Efe Ateş | Program Engineer | 16.05.2026

### REVISIONS

Rev. No Change Description | Date | QA Approval

Doc.No: 01-MIY-011 | Non - Contact Thermometer Acceptance Test Procedure | Rev1 | Page 3/14

## TABLE OF CONTENTS

Doc.No: 01-MIY-011 | Non - Contact Thermometer Acceptance Test Procedure | Rev1 | Page 4/14

### 1. SCOPE

The scope of this Acceptance Test Procedure is to formally validate the performance of the non-contact thermometer. The device will be tested against a controlled thermal plate and a commercial reference thermometer to verify its accuracy, operational controls, and functional limits.

### 2. REFERENCES

01-MIY-002: System Requirement Specification, Contact Body Thermometer 01-MIY-013: Verification-Validation Test Plan for Contact Body Thermometer

### 3. TEST EQUIPMENT AND SET-UP

### 3.1 TEST EQUIPMENT

NO | MODEL | DESCRIPTION | CALIBRATION
1 | DC Power Supply | DC Power Supply | NO
2 | Hot Plate | Temperature controlled hot plate | NO
3 | MLX90614 | Non- Contact Thermometer | YES
4 Reference | Thermometer | Handheld, off-the-shelf commercial infrared thermometer used to compare results. | NO
5 | PC | Connected to our thermometer to monitor and log the serial data and temperature readings. | NO

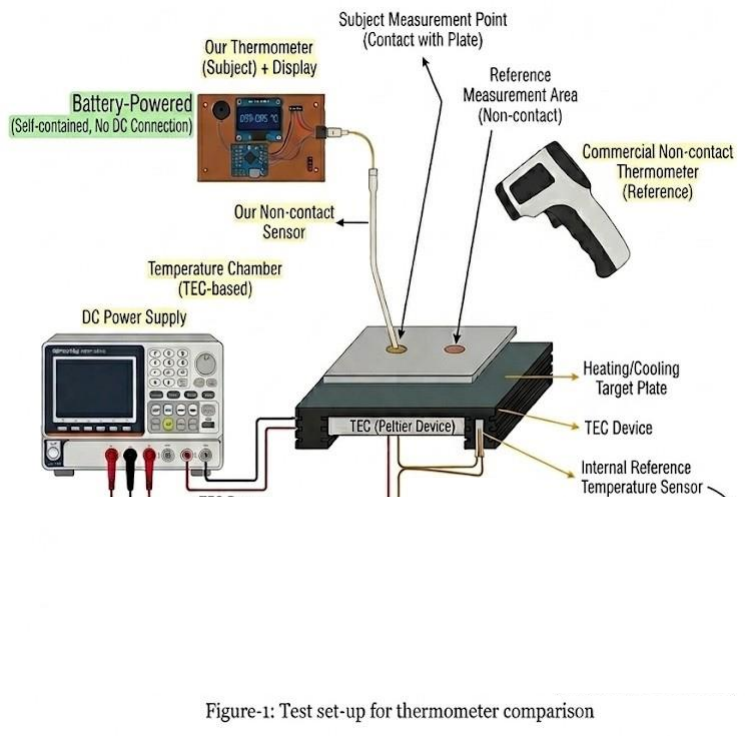
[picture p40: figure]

Doc.No: 01-MIY-011 | Non - Contact Thermometer Acceptance Test Procedure | Rev1 | Page 5/14

### 3.2 TEST SET-UP

### 4. TEST PROCEDURE

### 4.1 OPERATING CONTROLS

### 4.1.1 MODE SWITCH

1. Actuate the physical momentary push-button switch installed on thermometer.

Doc.No: 01-MIY-011 | Non - Contact Thermometer Acceptance Test Procedure | Rev1 | Page 6/14
2. Verify that the thermometer must reliably change its operational status.

### 4.1.2 TURN ON / AUTOMATIC TURN OFF

1. Make the connections as shown on Figure-1.
2. Ensure that the battery is properly connected to the thermometer circuit.
3 Turn the power switch to the ON position.
4. Verify that the OLED display powers on successfully.
5. Position the thermometer toward the target surface at the specified measurement distance.
6. Press the measurement button and verify that the temperature value is displayed correctly.
7. Leave the thermometer inactive after measurement completion.

### 4.2 ACCURACY

1. Make the connections as shown in Figure-1.
2. Ensure that the power supply connected to the hot plate is initially turned OFF.
3. Place the reference thermometer on the heated plate surface.
4. Turn ON the power supply and gradually heat the plate.
5. Monitor the reference thermometer until the hot plate temperature reaches 37°C, then turn OFF the power supply.
6. Wait until the temperature stabilizes. The plate may be considered stable when the reference thermometer temperature variation is less than 0.1°C for 10 seconds.
7. Turn ON the non-contact infrared thermometer (DUT).
8. Aim the infrared sensor toward the hot plate measurement surface from the defined measurement distance.
9. Measure the hot plate temperature simultaneously using both the reference thermometer and the DUT.
10. Record both measurement values.
11. Verify that the temperature difference between the reference thermometer and the DUT is less than ±0.3°C.

Doc.No: 01-MIY-011 | Non - Contact Thermometer Acceptance Test Procedure | Rev1 | Page 7/14

### 4.3 RATED OUTPUT RANGE

1. Make the connections as shown in Figure-1.
2. Ensure that the power supply output is initially disabled.
3. Turn ON the power supply and heat the hot plate until the reference thermometer reads 34°C.
4. Turn OFF the power supply and wait for temperature stabilization.
5. Turn ON the infrared thermometer and measure the hot plate temperature.
6. Record the measurements from both the reference thermometer and DUT.
7. Verify that the temperature difference is less than ±0.3°C.
8. Repeat Steps 1 through 7 by increasing the hot plate temperature to 43°C.
9 .Verify that the temperature difference remains less than ±0.3°C throughout the operating range.

### 4.4 UNITS OF MEASURE

1.Initialize the non-contact thermometer by toggling the power switch.

2.Observe the data presentation layout on the 0.96" OLED screen.

3.Verify that the measured temperature value is explicitly accompanied by the metric unit symbol for degrees Celsius: "°C".

### 4.5 MEASUREMENT TIME

1. Make the connections as shown in Figure-1.
2. Ensure that the hot plate temperature is stabilized at 37°C using the reference thermometer.
3. Keep the infrared thermometer at ambient room temperature for at least 10 minutes before testing.
4. Turn ON the thermometer device.
5. Aim the infrared sensor toward the hot plate surface from the specified measurement distance.
6. Press the measurement button to begin temperature acquisition.
7. Measure and record the elapsed time between pressing the button and displaying the final stable temperature reading.

Doc.No: 01-MIY-011 | Non - Contact Thermometer Acceptance Test Procedure | Rev1 | Page 8/14

### 4.6 ALARM CONDITIONS

### 4.6.1. COMPLETION OF MEASUREMENT

1.Completion of measurement is verified at the “Measurement Time” test.

### 4.6.2. OUTPUT TEMPERATURE OUTSIDE THE RATED OUTPUT RANGE

1. Configure the test bench by ensuring the reference (REF) thermometer is positioned directly on the heated plate surface.
2. Energize the power supply to heat the plate surface. Monitor the REF thermometer until the surface temperature reaches a baseline of 37°C, then adjust the power supply to maintain stability.
3. Power on the non-contact infrared thermometer (Device Under Test - DUT), align the infrared camera hole perpendicular to the plate at the operational distance, and press the measurement button.
4. Verify that the OLED display accurately registers and outputs the standard hot plate temperature.
5. Adjust the power supply (or allow the plate to cool) while observing the REF thermometer. When the plate surface temperature drops and stabilizes at 32°C lock in the state.
6. Align the infrared camera hole with the 32°C plate surface and press the measurement button.
7. Verify that the OLED display reliably prompts the low out-of-bounds indicator reading "Low".
8. Energize the power supply again to increase the temperature of the plate surface. Monitor the REF thermometer until the surface temperature reaches 40°C, then stabilize the input.
9. Align the infrared camera hole with the 40°C plate surface and press the measurement button.
10. Verify that the OLED display reliably prompts the high out-of-bounds indicator reading "High".

### 5. TEST REPORT

1. Test results will be recorded on the Acceptance Test Data Sheet in the Attachment-1

Doc.No: 01-MIY-011 | Non - Contact Thermometer Acceptance Test Procedure | Rev1 | Page 9/14

ACCEPTANCE TEST DATA SHEET

Assembly P/N: | 001-MIY-087 | Date: | 14.05.2026
Assembly S/N: | 001-MIY-089 | TestOperator: | Gülşen Demir
TestProcedure: | Acceptance Test | QA | Fadime Taş
ATP paragraph | Description | Test Limits | Measurement Result | Pass/Fail
4.1 | Physical Requirements
4.1.1 | Weight | Inspection | 113 gr | Pass
4.1.2 | Surface | Demonstration | Pla | Pass
4.2 | Functional Requirements
4.2.1 | Operating Controls | Test | Measurements are taken by pressing the buttons; otherwise, it stopstaking measurements. | Pass
4.2.2 | Power supply | Demonstration | 3.7 V rechargeable battery | Pass
4.2.3 | Units of Measure | Demonstration | °C | Pass
4.2.4 | Rated Output Range | Test | 25˚C to45˚C | Pass
4.2.5 | Measurement Time | Test | 0-1 seconds | Pass
4.2.6 | Alarm Conditions | Test | N/A | Fail
4.2.7 | Accuracy | Test | ±0.3 | Pass
4.3 | Environmental Conditions
4.3.1 | Operating Temperature | Test | 10˚C to40˚C | Pass
4.3.2 | Storage Temperature | Test | -25 ˚C to 55˚C | Pass
4.4 | Usability
4.4.1 | Display Size | Inspection | 0.96 inch | Pass
4.4.2 | Measuring Site | Demonstration | Forehead | Pass

### N/A: Not Applicable

Doc.No: 01-MIY-011 | Non - Contact Thermometer Acceptance Test Procedure | Rev1 | Page 10/14

INTERNAL AUDIT CHECK LIST*

Auditor: Fadime Taş | Signature:
No | Description | Check | CAR#
| RESPONSIBILITIES, AUTHORITY
1 | Project Organization Chart is available in Project Plan | +
2 | Job Description is made for Key Personnel in Project Plan | +
3 | Review & Approval Responsibilities are specified Project Plan | +
| DOCUMENT G DATA CONTROL
4 | Document Numbering System is established and applied for documentation | +
5 | Necessary documents are prepared, review & approved | +
6 | There is a document List | +
| PURCHASING
7 | BOM lists have sufficient information for purchasing | +
| PRODUCT IDENTIFICATION G TRACEABILITY
8 | Each component and assembly have a unique Part Number and has a serial number when necessary | +
| PROCESS CONTROL
9 | Technical & Engineering Specifications are available | +
10 | Applicable related Standards are referenced on documents | +
11 | Work Break Down Structure is available in Project Plan | +
| INCOMINGINSPECTIONGTEST
12 | In-house manufactured materials and Incoming materials are inspected | +
| IN-PROCESSINSPECTIONGTEST
13 | Quality ControlInspections & Test Plans are available | +
14 | Necessary test equipment is available in laboratories | +
| FINAL INSPECTION G TEST
15 | Test Procedures are sufficient to perform the tests | +
16 | Testresults and inspection results are documented
| CALIBRATION
17 | Calibration Certificates for equipment & devices are available | +
| CONTROL OF NON-CONFORMING PRODUCT
18 | Corrective-Preventive Action are taken for non-conforming materials | +
| CORRECTIVE G PREVENTIVE ACTIONS
19 | Corrective -Preventive Actions are taken for processes | +
20 | Non-conformity Follow-Up is implemented for Corrective Actions | +
21 | Corrective-Preventive Actions are closed appropriately | +
22 | Corr-Prev. Actions are reviewed during Review Meetings | +
| INTERNAL AUDIT
23 | Internal Audit is carried out and documented | +
*This check list is extracted from TMMOB MAKİNA MÜHENDİSLERİ ODASI "Internal Audit Check List"
- The audit shall be performed by Quality Assurance Engineer
- "Check" column shall be checked for acceptable processes
- A "Corrective Action Report" shall be initiated for non-conformances

Doc.No: 01-MIY-011 | Non - Contact Thermometer Acceptance Test Procedure | Rev1 | Page 11/14

NON-CONFORMINGMATERIALREPORT(NCMR)

NCMRNo: 1 | Date: 14.05.24 | Initiated by: PE
Part No: 1 | Description: Housing Assembly / Enclosure
Serial No: | Process: Identification, Correction, Documentation

Non-ConformanceDescription:During the KIT Placement assembly step, it was identified that the 3D-printed housing components were oversized. The internal cavity and mounting dimensions did not match the required specifications to securely hold the PCB and associated electronic hardware.
Inspection Findings: Improper Dimensions: The internal tolerances of the housing were too large, preventing the main board, display, and buttons from aligning properly with the exterior cutouts. The components could not be securely fixed within the enclosure.

Corrective Action: The 3D CAD model of the housing was revised to decrease the internal volume and adjust the dimensional tolerances for a precise fit. A new housing unit was fabricated using the updated model, allowing the assembly to be successfully completed.

Disposition: Rework or scrap and replace

MRB Approval | PE/PCE Approval for closure | Date: 16.05.2026

Rework

Repair* | QAE Approval for closure:
| Fadime Taş | CloseDate: 16.05.2026

Use As Is*

Doc.No: 01-MIY-011 | Non - Contact Thermometer Acceptance Test Procedure | Rev1 | Page 12/14

CORRECTIVE ACTION REPORT (CAR)

CAR Number: 1 | Process:
Reported by: Quality Assurance Engineer | 18.05.2026

Non-conformance Description:
Hardware Defect: The upper half of the OLED display is completely non-functional, restricting the available visual area for temperature readings and user interface elements..

Responsibility: Software Engineer

Root Cause: Root cause analysis identified physical damage or a hardware defect in the display module, which caused the top 32 pixel rows to fail.

Corrective Action Taken: To ensure continuous operation without immediate hardware replacement, the device's firmware was completely optimized. All graphical animations, temperature outputs, and status texts were strictly constrained to the functional bottom half of the screen, maintaining full readability and device usability.

Completion Date: 15.05.2026 | Responsible Signature:
QAE Disposition: | + Acceptable Not Acceptable
QAE Approval: | Closure Date: 15.05.2026

Doc.No: 01-MIY-011 | Non - Contact Thermometer Acceptance Test Procedure | Rev1 | Page 13/14

CORRECTIVE ACTION REPORT (CAR)

CAR Number: 2 | Process:
Reported by: Program Engineer | 16.05.2026

Non-conformance Description: Solder: During technical inspection, disconnected solder joints were detected on the component pins of the sensor and microcontroller feedback loops, causing inaccurate temperature readings.

Responsibility: Production Engineer

Root Cause:. Solder joint degradation over time caused increased resistance on the feedback loop component pins, leading to software/sensor communication errors.

Corrective Action Taken: Precision manual soldering rework was performed to repair all cold solder joints and bridges on the sensor and microcontroller units.

Completion Date: 17.05.2026 | Responsible Signature:
QAE Disposition: | + Acceptable Not Acceptable
QAE Approval: | Closure Date: 17.05.2026

Doc.No: 01-MIY-011 | Non - Contact Thermometer Acceptance Test Procedure | Rev1 | Page 14/14

CORRECTIVE ACTION REPORT (CAR)

CAR Number: 3 | Process:
Reported by: Program Engineer | 16.05.2026

Non-conformance Description: Solder: During technical inspection, and for better fit for inner space of 3d model we decided to change battery size and battery itself from 1000mAh to 120mAh. Brand name and voltage is same.

Responsibility: Production Engineer

Root Cause:. It would not fit into housing properly

Corrective Action Taken: New Battery equipped for thermometer

Completion Date: 17.05.2026 | Responsible Signature:
QAE Disposition: | + Acceptable Not Acceptable
QAE Approval: | Closure Date: 17.05.2026

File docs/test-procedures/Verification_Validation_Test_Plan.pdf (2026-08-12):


### ALL RIGHTS RESERVED. REPRODUCTION OR ISSUE TO THIRD PARTIES IN ANY FORM

WHATEVER IS NOT PERMITTED WITHOUT WRITTEN AUTHORITY FROM THE PROPRIETORS.

# Faculty of Engineering

# Department of Biomedical Engineering

# Non-Contact Type Clinical Thermometer Verification/Validation Test Plan

# PART NUMBER: 01-MIY-012

# REV: 1

# DATE:12.05.2026

Doc. No: 01-MIY-012 | Non - Contact Thermometer Verification/Validation Test Plan | Rev1 | Page 2/7

ALL RIGHTS RESERVED. REPRODUCTION OR ISSUE TO THIRD PARTIES IN ANY FORM WHATEVER IS NOT PERMITTED WITHOUT WRITTEN AUTHORITY FROM THE PROPRIETORS.

## CHANGE RECORDS

### FIRST RELEASE

CREATED BY

Name | Title | Date | Sign.
Fadime Taş | Quality Engineer | 12.05.2026

CHECKED BY

Name | Title | Date | Sign.
Gülşen Demir | System Engineer
| | 12.05.2026
APPROVED BY
Name | Title | Date | Sign.
Efe Ateş | Program Manager | 12.05.2026

### REVISIONS

Rev. No Change Description | Date | QA Approval

Doc. No: 01-MIY-012 | Non - Contact Thermometer Verification/Validation Test Plan | Rev1 | Page 3/7

## TABLE OF CONTENTS

Doc. No: 01-MIY-012 | Non - Contact Thermometer Verification/Validation Test Plan | Rev1 | Page 4/7

### 1. PURPOSE

The purpose of this document is to outline the formal engineering procedures and protocols required to verify and validate the design, hardware compilation, and firmware functionality of the Non-Contact Type Clinical Thermometer. This plan serves as the definitive structural guide for executing system evaluations, ensuring that the completed prototype complies entirely with the safety, performance, and operational boundaries defined in the System Requirements Document

### 2. SCOPE

The scope of this document encompasses the complete execution of verification and validation (V&V) testing methodologies applied directly to the prototype Non-Contact Type Clinical Thermometer (Part Number: 01-MIY-002). This includes testing the battery-powered hardware setup, the 3D-printed enclosure mechanics, the OLED display metrics, and the baseline tracking firmware.

V&V activities covered under this scope will be executed in an open laboratory setting using controlled heating/cooling plates, reference thermometers, and PC-based serial data loggers. A comprehensive Verification/Validation Matrix is included within this document to establish full traceability between each system requirement and its designated testing methodology.

### 3. REFERENCES

3.1. 01-MIY-002: System Requirements for Clinical IR Thermometer

Doc. No: 01-MIY-012 | Non - Contact Thermometer Verification/Validation Test Plan | Rev1 | Page 5/7

### 4. METHODS FOR VERIFICATION/VALIDATION

### 4.1 INSPECTION

Inspection refers to the visual, tactile, and dimensional examination of the hardware without actively operating the system. This method will be utilized to confirm physical compliance metrics, including:

- Verifying that the physical mass of the thermometer falls within the mandated 50g to 400g limits.
- Inspecting the 3D-printed housing for a smooth, cleanable, and defect-free surface finish.
- Manually checking that the user interface does not exceed the maximum limit of two operating buttons.
- Physically measuring the OLED display dimension to ensure it exceeds 0.96 inches.

### 4.2 ANALYSIS

Analysis encompasses the process of confirming whether a specification requirement has been met through thorough technical evaluation, mathematical calculations, and data processing rather than direct physical measurement alone. This method is utilized to evaluate complex system parameters and data.

Doc. No: 01-MIY-012 | Non - Contact Thermometer Verification/Validation Test Plan | Rev1 | Page 6/7

### 4.3. DEMONSTRATION

Demonstration involves a qualitative validation procedure aimed at showcasing the critical functions, user interactions, and visual capabilities of the system. Unlike rigorous testing, this process relies on clear pass/fail operational checks to exhibit usability and real-world performance, including:

- Operating the minimal, user-friendly control interface to prove that an individual can easily click and interact with the power and measurement switches.
- Observing the device behavior when left completely idle to demonstrate that the firmware successfully triggers an automatic power-saving or low-power sleep state within the designated timeline.
- Visually verifying the high-contrast output on the OLED screen to ensure that character sizes are larger than 4mm for easy reading and that the temperature values distinctly display the degrees Celsius metric

### 4.4. TEST

Testing involves a comprehensive, quantitative, and systematic examination of the thermometer under tightly controlled laboratory inputs. This methodology relies on calibrated measurement instruments and repeatable procedures to apply specific inputs, observe system responses, and meticulously evaluate the resulting data against strict numerical acceptance criteria.

- Formally validating that the thermometer successfully records temperatures across the target output range.
- Quantifying that the measurement acquisition time remains securely between 0 and 1 seconds.
- Subjecting the device to extreme environments inside an environmental chamber to verify operational stability and storage survival boundaries.

Doc. No: 01-MIY-012 | Non - Contact Thermometer Verification/Validation Test Plan | Rev1 | Page 7/7

### 4.5. VERIFICATION / VALIDATION MATRIX

The Verification/Validation Matrix contains the paragraph numbers and titles of requirement specifications, along with verification methods and procedures. Detailed instructions are provided within associated test procedures like the Acceptance Test Procedure (ATP) and Verification/Validation Test Procedure (V2TP). The creation of the Verification/Validation Test).

Verification/Validation Test Procedure will be created according to this plan.
System Requirement Specification paragraph 01-MIY-002 | Requirement Title | Method | Procedure

## 4.1 Physical Requiremets

4.1.1 | Weight | Inspection | V2TP
4.1.2 | Surface | Demonstration | V2TP

## 4.2 Functional Requirements

4.2.1 | Operating Controls | Test | ATP
4.2.2 | Power supply | Demonstration | V2TP
4.2.3 | Units of Measure | Demonstration | ATP
4.2.4 | Rated Output Range | Test | ATP
4.2.5 | Accuracy | Test | ATP
4.2.6 | Measurement Time | Test | ATP
4.2.7 | Alarm Conditions | Test | ATP, V2TP

## 4.3 Environmental Conditions

4.3.1 | Operating Temperature | Test | V2TP
4.3.2 | Storage Temperature | Test | V2TP

## 4.4 Usability

4.4.1 | Display Size | Inspection | V2TP
4.4.2 | Measuring Site | Demonstration | V2TP

Table-1: Verification/Validation matrix.

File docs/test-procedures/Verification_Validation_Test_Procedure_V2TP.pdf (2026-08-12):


### ALL RIGHTS RESERVED. REPRODUCTION OR ISSUE TO THIRD PARTIES IN ANY FORM WHATEVER IS NOT PERMITTED WITHOUT WRITTEN AUTHORITY FROM THE

PROPRIETORS.

# Faculty of Engineering

# Department of Biomedical Engineering

# Non-Contact Type Clinical Thermometer Verification/Validation Test Procedure (V2TP)

# PART NUMBER: 01-MIY-013

# REV: 1

# DATE:20.05.2026

Doc. No: 01-MIY-013 Non - Contact Thermometer Verification/Validation Test
Procedure (V2TP)

Rev1 Page 2/8

ALL RIGHTS RESERVED. REPRODUCTION OR ISSUE TO THIRD PARTIES IN ANY FORM WHATEVER IS NOT PERMITTED WITHOUT WRITTEN AUTHORITY FROM THE PROPRIETORS.

## CHANGE RECORDS

### FIRST RELEASE

CREATED BY

Name | Title | Date | Sign.
Gülşen Demir | System Engineer | 16.05.2026

CHECKED BY

Name | Title | Date | Sign.
Fadime Taş | Quality Engineer
| | 16.05.2026
APPROVED BY
Name | Title | Date | Sign.
Efe Ateş | Program Manager | 16.05.2026

### REVISIONS

Rev. No Change Description | Date | QA Approval

Doc. No: 01-MIY-013 | Non - Contact Thermometer Verification/Validation Test
Rev1 | Page 3/8

## TABLE OF CONTENTS

Doc. No: 01-MIY-013 | Non - Contact Thermometer Verification/Validation Test
Rev1 | Page 4/8

### 1. SCOPE

Validation is the confirmation that the requirements of clinical thermometer have been fulfilled through clinical tests on actual subjects (patients), using statistical methods where the verification is the confirmation that the requirements of clinical thermometer have been
fulfilled through laboratory tests using a reference temperature source.

For a clinical thermometer that operates in the adjusted mode, the laboratory accuracy is verified in a direct mode and the clinical accuracy is validated in the operating mode with a sufficiently large group of human subjects.

### 2. REFERENCES

2.1 ISO 80601-2-56:2017 : Part 2-56: Particular requirements for basic safety and essential performance of clinical thermometers for body temperature measurement
2.2 01-MIY-002: System Requirement Specification, Contact Body Thermometer
2.3 01-MIY-012: Verification-Validation Test Plan for Contact Body Thermometer
2.4 01-MIY-011: Acceptance Test Procedure

### 3. VERIFICATION TESTS

Most of the requirements to be verified within the scope of verification tests are covered by the Acceptance Test Procedure. Therefore, the first step of the verification activities is the successful completion of the acceptance tests. Following successful completion, the remaining tests, inspections, and demonstrations specified in the Verification/Validation Matrix shall be performed.

### 3.1. FUNCTIONAL TESTS

Run the acceptance tests as per 01-MIY-011, Acceptance Test Procedure and record the results in Verification/Validation Test Data Sheet given in attachment-1

Doc. No: 01-MIY-013 | Non - Contact Thermometer Verification/Validation Test
Rev1 | Page 5/8

### 3.2. WEIGHT

The weight of the thermometer was measured using a calibrated precision scale. The measured total weight of the device was determined to be 79 grams, which is within the specified limit of 200 grams. The result confirms compliance with the weight requirement and demonstrates suitability for handheld operation.

### 3.3. SURFACE

Demonstrate that there is no malfunction, no damage or color changes after cleaning the thermometer with a IPA alcohol.

### 3.4. OPERATING TEMPERATURE

Operating temperature testing was conducted for the non-contact clinical thermometer. The device was verified to operate correctly within the intended temperature measurement range of 10°C to 40°C.

The thermometer maintained stable operation and accurate temperature measurement performance throughout the specified range.

### 3.5. STORAGE TEMPERATURE

Storage temperature testing was not performed for this project due to the unavailability of a suitable environmental temperature chamber.

### 3.6. DISPLAY SIZE

The temperature reading on the screen will be measured with a scale to verify that the characters at least 4mm height and readable.

### 3.7. MEASURING SITE

The thermometer is designed as a non-contact infrared clinical thermometer. Temperature measurements are obtained remotely by aiming the infrared sensor toward the target measurement area without physical contact.

Doc. No: 01-MIY-013 | Non - Contact Thermometer Verification/Validation Test
Rev1 | Page 6/8

### 3.8. POWER SUPPLY

3.8.1.

Connect the USB Type-C connector of the 5 VDC adapter to the USB Type-C charging port of the thermometer.

3.8.2.

Verify that the charging indicator LED turns on, indicating that battery charging has started.

3.8.3.

After sufficient charging time, verify that the charging indicator changes state, indicating completion of battery charging.

3.8.4.

Disconnect the 5 VDC adapter and verify that the thermometer continues operating using its internal battery.

3.8.5.

Verify that all measurement and display functions continue to operate normally while powered only by the internal battery.

### 4. VALIDATION TESTS

The clınıcal accuracy of the non-contact clinical thermometer shall be validated using measurements obtained under controlled conditions and compared with a calibrated reference thermometer.

Statistical evaluation methods shall be used to compare the output temperatures of the Device Under Test (DUT) with those of the Reference Clinical Thermometer (RCT).

Within the scope of validation testing, the following parameters shall be evaluated:

- Clinical Bias (Δcb)
- Limits of Agreement (LA)
- Clinical Repeatability (σr)

Doc. No: 01-MIY-013 | Non - Contact Thermometer Verification/Validation Test
Rev1 | Page 7/8

### 4.1. CLINICAL ACCURACY TESTS

Clinical accuracy validation methods, procedures, and calculations shall be performed in accordance with ISO 80601-2-56:2017, Part 2-56, Clause 201.102 (Clinical Accuracy Validation).

The results for Clinical Bias (Δcb), Limits of Agreement (LA), and Clinical Repeatability (σr) shall be documented in the Verification/Validation Test Data Sheet provided in Attachment-1.

### 5. TEST REPORT

Test results will be recorded on the Acceptance Test Data Sheet in the Attachment-1

Doc. No: 01-MIY-013 | Non - Contact Thermometer Verification/Validation Test
Rev1 | Page 8/8

ATTACHMENT-1: VERIFICATION/VALIDATION TEST DATA SHEET

VERIFICATION/VALIDATION TEST DATA SHEET

Assembly P/N: | 01-MIY-015 | Date: | 20.05.2026
Assembly S/N: | 01-MIY-090 | TestOperator: | Gülşen Demir
TestProcedure: | Verification/Validation | QA | Fadime Taş
ATP paragraph | Description | TestLimits | Measurement Result | Pass/Fail
ATP para 4.1 | Operating Controls | N/A | TRUE | Pass
ATP para 4.1.1 | MODEswitch | Toggle the mode | TRUE | Pass
ATP para 4.1.2 | POWERON/OFF | Display Temperature | TRUE | Pass
ATP para 4.1.2 | Automatic Turn Off | Turn off time < 5 sec | TRUE | Pass
ATP para 4.2 | Accuracy | <0.3°C | 0.3 | Pass
ATP para 4.3 | Rated Output Range | 25 °C< T < 45°C | TRUE | Pass
ATP para 4.4 | Units of Measure | °C | TRUE | Pass
ATP para 4.5 | Measurement Time | <2sec | TRUE | Pass
ATP para 4.6 | Alarm Conditions | N/A | FALSE | Fail
ATP para 4.6.1 | Completion of measurement | Sound alarm | FALSE | Fail
ATP para 4.6.2 | Below The Tange | Blue Display | TRUE | Pass
ATP para 4.6.2 | Above The Range | Red Display | TRUE | Pass
V2TP para 3.2 | Weight | <200gr | TRUE | Pass
V2TP para 3.3 | Surface | Demonstrate | TRUE | Pass
V2TP para 3.4 | Operating Temperature | N/A | (15 to 45) c | Pass
V2TP para 3.5 | Storage Temperature | N/A | (-25 to 90) c | Pass
V2TP para 3.6 | Display Size | >=4mm | 30mm | Pass
V2TP para 3.7 | Measuruing Site | Demonstrate | wrist, forehead | Pass
V2TP para 3.8 | Power Supply | Rechargable | TRUE | Pass
V2TP para 4.1 | Clinical Bias, Δcb | 1.81 | | Pass
V2TP para 4.1 | Limits of Agreement, LA | -2.76 to 0.87 | | Pass
V2TP para 4.1 | Clinical Repeatability, σr | 0.12 | | Pass
| | Completion Date: 20.05.2026

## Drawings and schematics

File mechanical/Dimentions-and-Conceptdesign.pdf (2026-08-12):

1

A

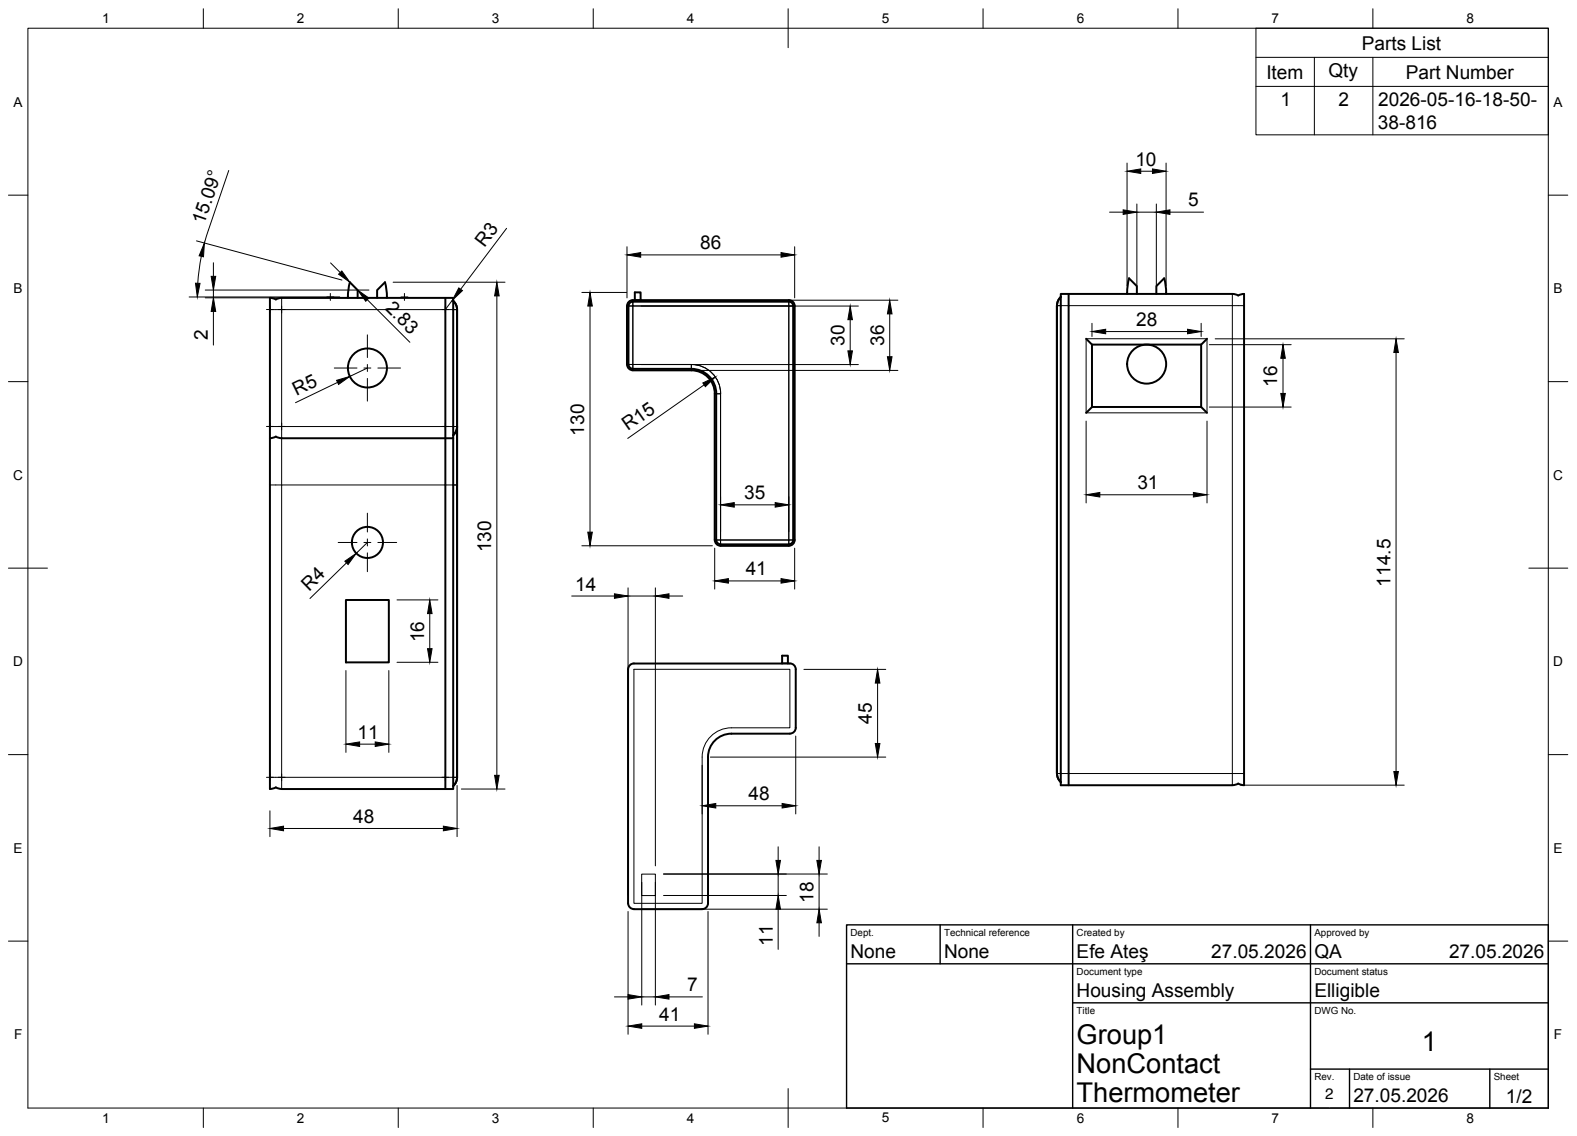
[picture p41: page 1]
BCDEF; ABCDEF; Dept.; Technical reference; Created by; Approved by; Document type; Document status; Title; DWG No.; Rev.; Date of issue; Sheet; Thermometer; Housing Assembly; Elligible; NonContact; Group1; None; Efe Ateş; Parts List; Item; Qty; Part Number 1

1

A

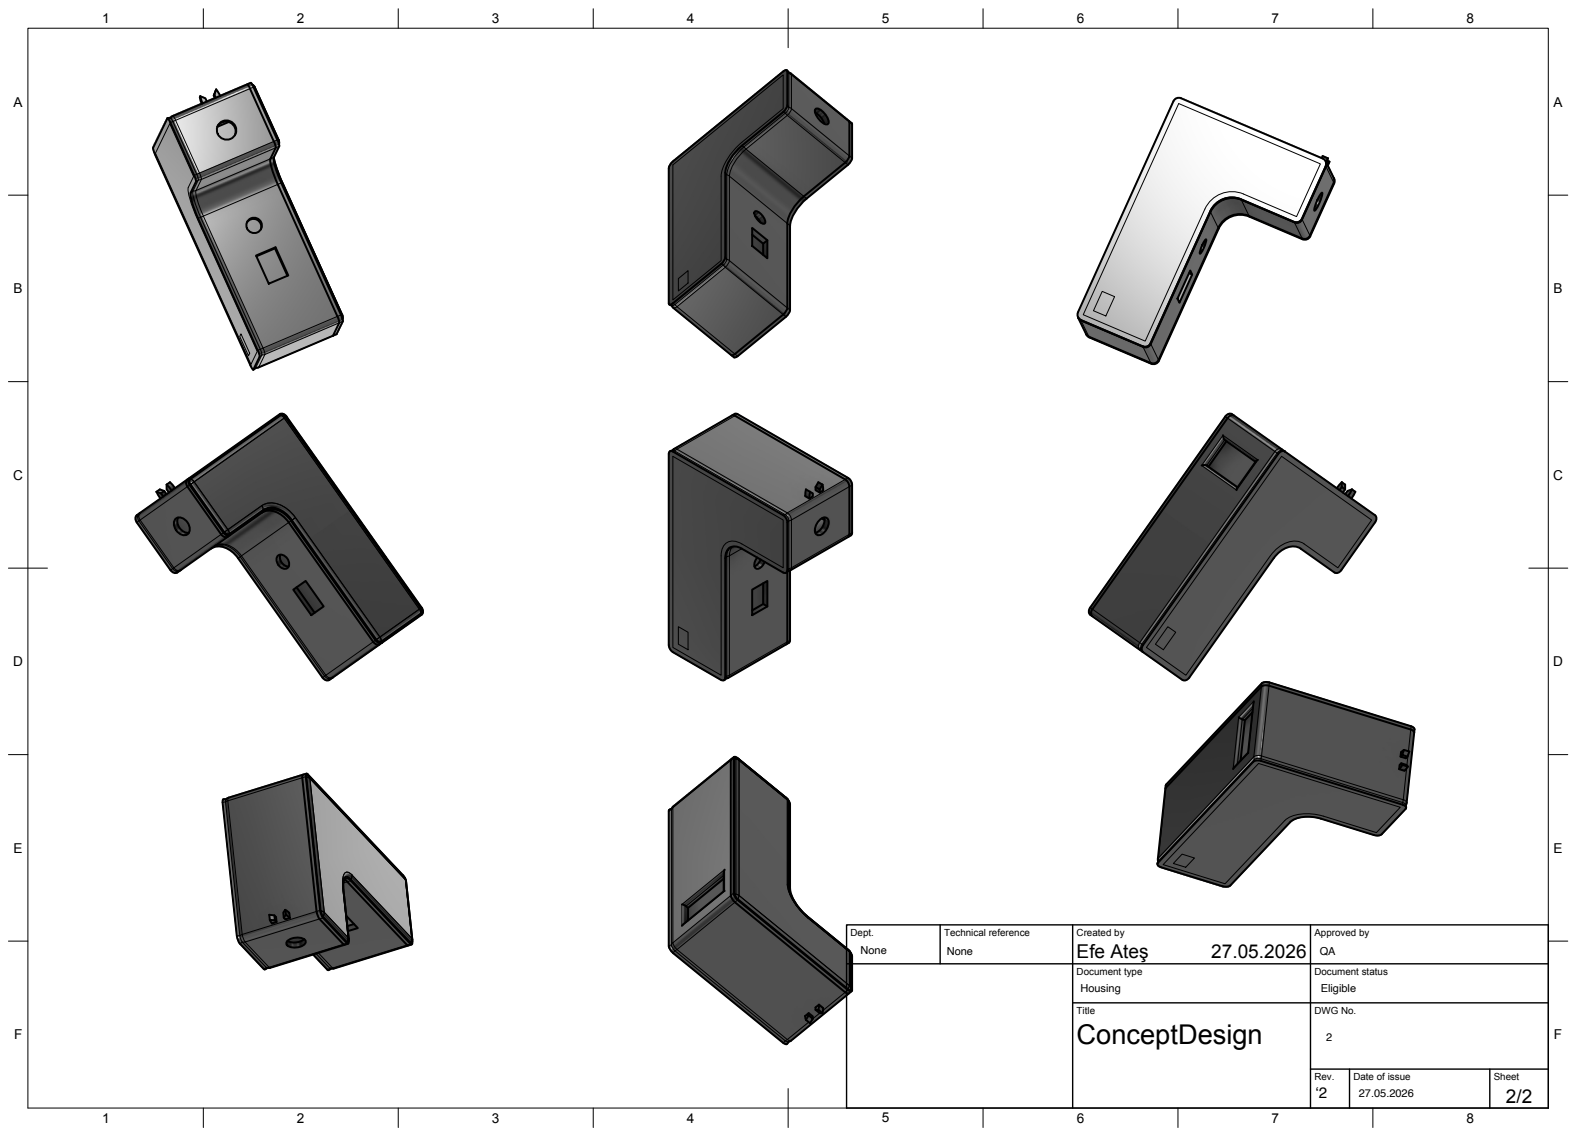
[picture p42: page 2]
Dept.; Technical reference; Created by; Approved by; Document type; Document status; Title; DWG No.; Rev.; Date of issue; Sheet; ConceptDesign; Efe Ateş

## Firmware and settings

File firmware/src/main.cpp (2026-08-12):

/**
 * @file main.cpp
 * @brief Firmware for Clinical Non-Contact IR Thermometer (ESP32-C3)
 * @details Measures body/object temperature using Melexis MLX90614 IR sensor
 *          and displays results on an SSD1306 OLED display with audio alerts.
 * 
 * Target Board: ESP32-C3 Mini
 * Peripherals: MLX90614 (I2C), SSD1306 OLED (I2C), Active Buzzer, Push Button
 * Compliance: EN ISO 80601-2-56 Compliant Measurement Logic
 */

#include <Wire.h>
#include <Adafruit_MLX90614.h>
#include <Adafruit_GFX.h>
#include <Adafruit_SSD1306.h>
#include <math.h>

// ==========================================
// Hardware Pin & I2C Configuration
// ==========================================
constexpr uint8_t PIN_I2C_SDA       = 8;
constexpr uint8_t PIN_I2C_SCL       = 9;
constexpr uint8_t PIN_BUZZER        = 0;
constexpr uint8_t PIN_BUTTON        = 21;

constexpr uint32_t I2C_CLOCK_SPEED   = 50000; // 50 kHz for stable IR sensor readouts
constexpr uint8_t OLED_I2C_ADDRESS  = 0x3C;

// ==========================================
// Display & Measurement Parameters
// ==========================================
constexpr uint8_t SCREEN_WIDTH      = 128;
constexpr uint8_t SCREEN_HEIGHT     = 64;
constexpr int8_t  OLED_RESET_PIN    = -1;

constexpr float FEVER_THRESHOLD_C   = 37.5f;   // Fever threshold in Celsius
constexpr uint32_t RESULT_HOLD_TIME_MS = 4000; // Display result hold duration (4s)

// ==========================================
// Global Peripheral Instances
// ==========================================
Adafruit_MLX90614 mlx = Adafruit_MLX90614();
Adafruit_SSD1306 display(SCREEN_WIDTH, SCREEN_HEIGHT, &Wire, OLED_RESET_PIN);

// ==========================================
// Function Declarations
// ==========================================
void playStartupAnimation();
void showLoadingSpinner(int durationMs);
void displayResultSlideIn(double objTemp, double ambTemp);
void triggerFeverAlert(double objTemp, double ambTemp);
void updateIdleHeartbeat();
void playButtonBeep();

// ==========================================
// Audio Feedback Helper
// ==========================================

/**
 * @brief Plays a short auditory feedback pulse on button press.
 */
void playButtonBeep() {
    digitalWrite(PIN_BUZZER, HIGH);
    delay(80);
    digitalWrite(PIN_BUZZER, LOW);
}

// ==========================================
// Display UI & Animation Modules
// ==========================================

/**
 * @brief Plays the initial boot-up thermometer filling animation and welcome screen.
 */
void playStartupAnimation() {
    // Fill thermometer tube animation
    for (int h = 0; h <= 36; h += 2) {
        display.clearDisplay();
        display.drawRoundRect(58, 4, 12, 40, 3, SSD1306_WHITE);
        display.fillCircle(64, 50, 8, SSD1306_WHITE);
        if (h > 0) {
            display.fillRect(60, 42 - h, 8, h, SSD1306_WHITE);
        }
        display.setTextSize(1);
        display.setCursor(2, 20);
        display.print("G1-MIY");
        display.setCursor(2, 34);
        display.print("Thermometer");
        display.display();
        delay(35);
    }
    delay(200);

    // Full thermometer display pulse
    display.clearDisplay();
    display.fillCircle(64, 50, 8, SSD1306_WHITE);
    display.fillRect(60, 6, 8, 36, SSD1306_WHITE);
    display.drawRoundRect(58, 4, 12, 40, 3, SSD1306_WHITE);
    display.display();
    delay(300);

    // Welcome text slide-in animation
    for (int x = 128; x >= 10; x -= 10) {
        display.clearDisplay();
        display.setTextSize(2);
        display.setCursor(x, 18);
        display.print("WELCOME");
        display.setTextSize(1);
        display.setCursor(x + 5, 42);
        display.print("G1-MIY Thermometer");
        display.display();
        delay(20);
    }
    delay(1500);
}

/**
 * @brief Renders a rotating loading spinner while temperature is acquired.
 * @param durationMs Duration of the spinner animation in milliseconds.
 */
void showLoadingSpinner(int durationMs) {
    const int cx = 64, cy = 28, r = 16;
    int steps = durationMs / 70;

    for (int s = 0; s < steps; s++) {
        display.clearDisplay();
        display.setTextSize(1);
        display.setCursor(22, 52);
        display.print("Measuring...");

        for (int i = 0; i < 8; i++) {
            float angle = radians(((i + s) % 8) * 45.0);
            int px = cx + r * cos(angle);
            int py = cy + r * sin(angle);

            if (i == 7) {
                display.fillCircle(px, py, 3, SSD1306_WHITE);
            } else if (i >= 5) {
                display.fillCircle(px, py, 2, SSD1306_WHITE);
            } else {
                display.drawPixel(px, py, SSD1306_WHITE);
            }
        }
        display.display();
        delay(10);
    }
}

/**
 * @brief Smoothly slides temperature measurement results onto the OLED screen.
 * @param objTemp Target object / body temperature in Celsius.
 * @param ambTemp Ambient environment temperature in Celsius.
 */
void displayResultSlideIn(double objTemp, double ambTemp) {
    for (int offset = 128; offset >= 0; offset -= 14) {
        display.clearDisplay();
        display.setTextSize(1);
        display.setCursor(offset, 0);
        display.print("Environment: ");
        display.print(ambTemp, 1);
        display.print("C");
        display.drawLine(offset, 12, offset + 128, 12, SSD1306_WHITE);

        display.setTextSize(3);
        display.setCursor(offset + 5, 18);
        display.print(objTemp, 1);
        
        display.setTextSize(2);
        display.setCursor(offset + 92, 18);
        display.print((char)247); // Degree symbol (°C)
        display.print("C");

        display.setTextSize(1);
        if (objTemp >= FEVER_THRESHOLD_C) {
            display.setCursor(offset + 28, 52);
            display.print("!  FEVER  !");
        } else {
            display.setCursor(offset + 40, 52);
            display.print("Normal");
        }
        display.display();
        delay(12);
    }
}

/**
 * @brief Triggers acoustic and visual fever warning (4 distinct beeps).
 * @param objTemp Target object / body temperature in Celsius.
 * @param ambTemp Ambient environment temperature in Celsius.
 */
void triggerFeverAlert(double objTemp, double ambTemp) {
    // 4-cycle auditory & visual alert (~1 second total duration)
    for (int i = 0; i < 4; i++) {
        display.clearDisplay();
        display.setTextSize(1);
        display.setCursor(0, 0);
        display.print("Environment: ");
        display.print(ambTemp, 1);
        display.print("C");
        display.drawLine(0, 12, 128, 12, SSD1306_WHITE);

        display.setTextSize(3);
        display.setCursor(5, 18);
        display.print(objTemp, 1);
        
        display.setTextSize(2);
        display.setCursor(92, 18);
        display.print((char)247);
        display.print("C");

        display.setTextSize(1);
        display.setCursor(28, 52);
        display.print("!  FEVER  !");
        display.display();

        digitalWrite(PIN_BUZZER, HIGH);
        delay(100);
        digitalWrite(PIN_BUZZER, LOW);
        delay(150);
    }
}

/**
 * @brief Renders the non-blocking heartbeat animation on the standby idle screen.
 */
void updateIdleHeartbeat() {
    static unsigned long lastFrame = 0;
    static int frame = 0;
    static int dir = 1;

    if (millis() - lastFrame < 55) return;
    lastFrame = millis();

    frame += dir;
    if (frame >= 7 || frame <= 0) {
        dir = -dir;
    }

    display.clearDisplay();

    // Heart icon rendering
    int hx = 55, hy = 8;
    int r = (frame > 3) ? 6 : 4;
    display.fillCircle(hx, hy, r, SSD1306_WHITE);
    display.fillCircle(hx + r * 2, hy, r, SSD1306_WHITE);
    display.fillTriangle(hx - r, hy + r / 2,
                         hx + r * 3 + r, hy + r / 2,
                         hx + r, hy + r * 2 + 2, SSD1306_WHITE);

    display.setTextSize(1);
    display.setCursor(8, 32);
    display.print("Press the button");
    display.setCursor(22, 46);
    display.print("to measure");

    // Dynamic loading dots
    for (int d = 0; d < 3; d++) {
        if (frame > d * 2) {
            display.fillCircle(50 + d * 10, 58, 2, SSD1306_WHITE);
        }
    }
    display.display();
}

// ==========================================
// Setup & Initialization
// ==========================================
void setup() {
    Serial.begin(115200);
    delay(1000);

    // Pin mode initialization
    pinMode(PIN_BUTTON, INPUT_PULLUP);
    pinMode(PIN_BUZZER, OUTPUT);
    pinMode(PIN_I2C_SDA, INPUT_PULLUP);
    pinMode(PIN_I2C_SCL, INPUT_PULLUP);
    delay(100);

    // Initialize I2C bus with custom speed
    Wire.begin(PIN_I2C_SDA, PIN_I2C_SCL);
    Wire.setClock(I2C_CLOCK_SPEED);
    delay(100);

    // Initialize OLED Display
    if (!display.begin(SSD1306_SWITCHCAPVCC, OLED_I2C_ADDRESS)) {
        Serial.println("[ERROR] OLED Display initialization failed!");
        while (true);
    }
    display.setTextColor(SSD1306_WHITE);

    // Play bootup sequence
    playStartupAnimation();

    // Initialize MLX90614 Sensor
    if (!mlx.begin(MLX90614_I2CADDR, &Wire)) {
        Serial.println("[ERROR] MLX90614 IR Sensor initialization failed!");
        display.clearDisplay();
        display.setCursor(10, 25);
        display.print("SENSOR ERROR!");
        display.display();
        while (true);
    }

    Serial.println("[INFO] Thermometer System Ready!");
}

// ==========================================
// Main Application Loop
// ==========================================
void loop() {
    // Render idle heartbeat animation when waiting
    updateIdleHeartbeat();

    // Check measurement trigger button (active LOW)
    if (digitalRead(PIN_BUTTON) == LOW) {
        delay(50); // Debounce delay
        if (digitalRead(PIN_BUTTON) == LOW) {

            // 1. Audio feedback for button press
            playButtonBeep();

            // 2. Display acquisition spinner
            showLoadingSpinner(1500);

            // Read temperatures
            double objTemp = mlx.readObjectTempC();
            double ambTemp = mlx.readAmbientTempC();

            Serial.print("[LOG] Object: "); Serial.print(objTemp);
            Serial.print(" °C | Environment: "); Serial.print(ambTemp); Serial.println(" °C");

            if (!isnan(objTemp)) {
                // 3. Display result slide-in animation
                displayResultSlideIn(objTemp, ambTemp);

                // 4. Trigger fever warning if above threshold
                if (objTemp >= FEVER_THRESHOLD_C) {
                    delay(500);
                    triggerFeverAlert(objTemp, ambTemp);
                }
            }

            // Wait until button release
            while (digitalRead(PIN_BUTTON) == LOW);

            // Hold result on display for 4 seconds (interruptible by new press)
            unsigned long holdStart = millis();
            while (millis() - holdStart < RESULT_HOLD_TIME_MS) {
                if (digitalRead(PIN_BUTTON) == LOW) {
                    break;
                }
                delay(10);
            }
            delay(50);
        }
    }
}

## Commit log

2026-08-12 minor error fixes, added model
    [Fusion360ModelofIRClinicalThermo.f3z, Thermometer-Refined-Cover.stl, Thermometer-Refined-body.stl]
2026-08-12 enhanced delivery in mechanical directory
    [Thermometer-Refined-Cover.stl, termometrekapak-refined.stl]
